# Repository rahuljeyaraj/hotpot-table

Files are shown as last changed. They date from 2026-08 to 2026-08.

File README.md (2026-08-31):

<p align="center">
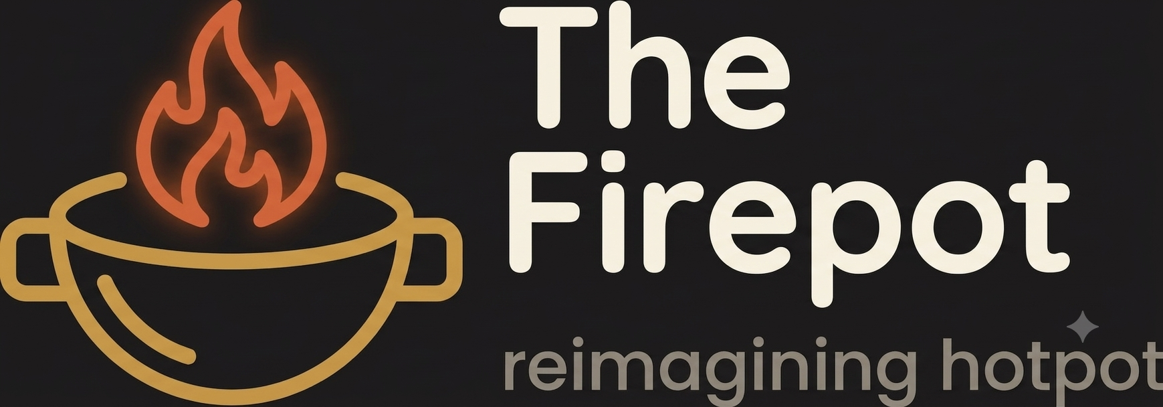
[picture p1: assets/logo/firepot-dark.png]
The Firepot — reimagining hotpot
  
</p>

<h1 align="center">The Firepot</h1>

<p align="center">
  A self-serve hotpot counter that weighs your bowl, prices it as you fill it, and sets itself on fire. Responsibly.
</p>

---

Eight ingredient bins are set into a tabletop of projector screen fabric. A
projector hangs above and lights the whole surface; a camera beside it watches
your hands. Every name, price, calorie count, tasting note, cart line and the
entire checkout is projected light landing on the table itself — right where a
person stands with a bowl in one hand and tongs in the other.

Each bin sits on a load cell. Take 60 g of dried eel and the cart on the near
edge of the table says so, priced, before you have put the tongs down. Tip some
back and the number falls. Pick a broth, pick a spice level, and a QR code
appears on the table for an itemised receipt on your own phone.

The whole interface is projected. There is no screen, no kiosk and nothing to
touch.

> **Build guide:** [`docs/HACKSTER.md`](docs/HACKSTER.md) is the full write-up —
> the story, the bill of materials, the wiring, the plywood cutting plan, and
> what the thing feels like to use.

---

## How it works

<p align="center">
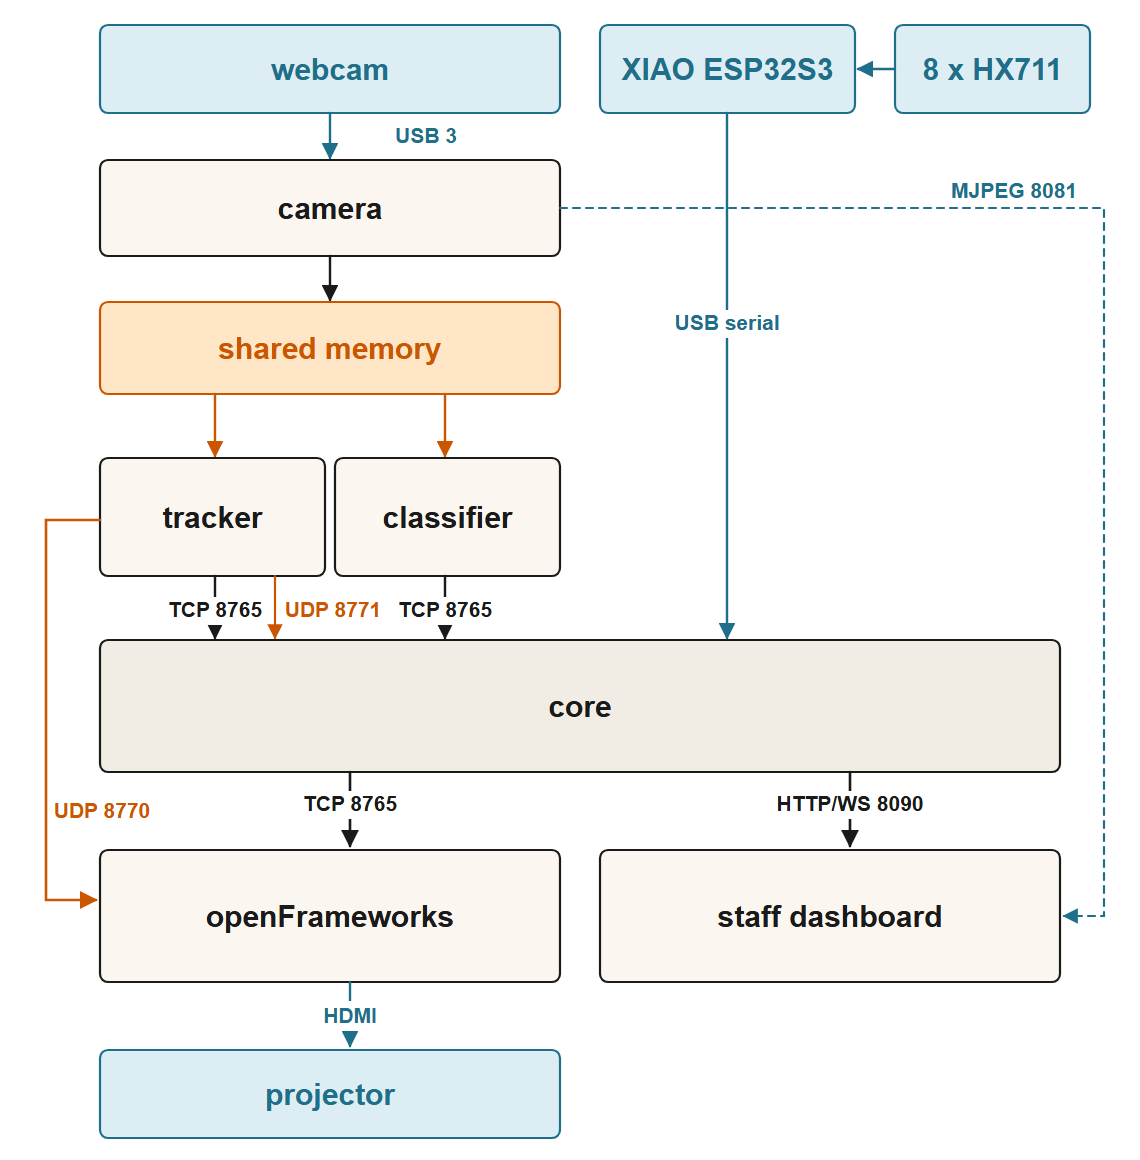
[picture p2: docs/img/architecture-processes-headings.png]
Five processes and four transports, from the webcam and load cells down to the projector
  
</p>

Five processes, none of which shares a variable with any other. `python run.py`
starts and supervises all of them, waits for each to report ready, merges every
log into one stream, and restarts anything that dies. Every process reconnects
forever, so any of them can come and go while the table carries on.

| Process | What it owns |
| --- | --- |
| `core` | Every price, every rule and every word. The state machine, the cart, the load cells, the orders database, the staff dashboard. |
| `of` | The projected table. A dumb renderer — it draws what it is told and holds no opinion. |
| `camera` | Frame capture, exposure/white-balance control, the shared-memory frame ring, and an MJPEG stream for the dashboard. |
| `tracker` | MediaPipe hand tracking over a window that follows the hand, emitting one cursor in projector pixels. |
| `classifier` | Bin crops, dataset capture, and ingredient recognition. |

A sixth process, `voice`, is started alongside these but is still a stub — it
connects, heartbeats and does nothing else.

Three kinds of traffic get three kinds of transport, each chosen for how the
data goes stale:

- **Cursor packets** go over UDP and the reader drains the socket, keeps the
  newest and throws the rest away. A queued cursor is worse than a lost one —
  the hand visibly walks back through its own history.
- **Camera frames** are six megabytes each, thirty times a second, so they go
  through a shared-memory ring with a seqlock. `core` never imports that
  module at all; the process that handles money has no way to touch a pixel.
- **State and control** go over TCP JSONL, one message per line.

There is exactly one coordinate system on the wire — projector pixels,
1920×1080 — so no two processes can disagree about where a bin is.

Further reading: [`docs/HOTPOT_ARCHITECTURE_v3.md`](docs/HOTPOT_ARCHITECTURE_v3.md)
is the authoritative design document; [`docs/VISUAL_LAYER.md`](docs/VISUAL_LAYER.md)
covers the renderer.

## Hardware

- **8 ×** 1 kg load cells with HX711 amplifiers, one per bin
- **1 ×** Seeed Studio XIAO ESP32S3, streaming all eight channels over USB
- **1 ×** 1080p projector, mounted on the wall right against the ceiling and
  aimed straight down, covering the full 1524 mm width of the table; squared
  up with its own 4D keystone
- **1 ×** 1080p webcam, zip-tied to a batten off the projector's mount and
  looking down at the same table — it hangs upside down on this build
- **1 ×** mini PC host (developed against an ASUS NUC 14 running Windows 11)
- Plywood, projector screen fabric, and a kilogram of gold PLA

Printable parts (`.3mf` plates, ready to slice) are in
[`hardware/3d-printed/`](hardware/3d-printed/); the KiCad project for the
load-cell harness is in [`hardware/firepot-loadcells/`](hardware/firepot-loadcells/).
The bill of materials with links, the wiring, and the cutting plan are all in
[`docs/HACKSTER.md`](docs/HACKSTER.md).

## Repository layout

```
config/            system.json — ports, thresholds, device selection
data/              catalogue.json, menu.json, locales/{en,zh}.json
firmware/loadcells/  PlatformIO firmware for the XIAO
hardware/          3D-printable parts and the KiCad schematic
of/hotpot-table/   the openFrameworks app (the projected table)
python/hotpot/     core, camera, tracker, classifier, voice, common
python/tests/      the unit test suite
tools/             dataset export, diagram rendering, rig utilities
run.py             the launcher and supervisor
```

## Getting started

### 1. Put it inside an openFrameworks tree

The Visual Studio project walks five levels up to find openFrameworks, so this
repository has to live at `apps/myApps/hotpot-table`. Download
[openFrameworks 0.12.1](https://openframeworks.cc/download/), unzip it, and
clone into it:

```
cd openFrameworks/apps/myApps
git clone https://github.com/rahuljeyaraj/hotpot-table
```

### 2. Build the table

`ofxGui`, `ofxOsc` and `ofxNetwork` ship with openFrameworks.
[ofxFlowTools](https://github.com/moostrik/ofxFlowTools) — the fluid solver
behind the fire — is a separate download into `openFrameworks/addons/`, and it
needs a patch before it will build:

```
cd openFrameworks/addons/ofxFlowTools
git apply ../../apps/myApps/hotpot-table/of/patches/ofxFlowTools.patch
```

The patch replaces two constructs the current compiler rejects, and fixes a
density lookup in the buoyancy and diffusion shaders that samples a texture at
a different resolution from the one it renders at.

Then open `of/hotpot-table/hotpot-table.sln` and build the **Debug**
configuration — that is the binary the launcher starts. Set `HOTPOT_OF_BIN` to
run something else.

### 3. Install the Python side

One interpreter for the whole tree:

```
pip install -r python/requirements.txt
```

### 4. Flash the XIAO

```
cd firmware/loadcells
pio run -t upload
pio device monitor
```

A working board probes all eight cells and then streams `raw <c0> ... <c7>` at
115200 baud. If a cell is missing, the probe names the pin and says whether the
data line is floating (open wire or unpowered HX711) or driven high (check the
clock).

### 5. Point it at your own rig

Three values:

- `SCALE_PORT` in `python/hotpot/core/main.py` — the XIAO's serial port.
  `pio device monitor` names yours.
- `camera.windows_device_index` in `config/system.json` — which webcam.
- `of/hotpot-table/bin/data/display.txt` — the projector's desktop origin as
  `x,y`. Start the app once; it writes the file and logs every monitor it found
  with its origin, so you can fill in the right one.

## Running

```
python run.py
```

Everything starts, in order, with one merged log to the terminal and to
`logs/hotpot-<date>.log`.

| | |
| --- | --- |
| `python run.py --replace` | stop whatever is running, start fresh |
| `python run.py --stop` | stop a detached instance |
| `python run.py --only core,of` | start the table alone, camera unplugged |
| `python run.py --no-restart` | leave a crashed process dead so you can read its traceback |

The staff dashboard is at `http://<host>:8090` from any device on the same
network, phone included.

## The staff dashboard

A **Serving** switch at the top opens and closes the table. Turn it off and
nothing bills, so staff can reach across the bins and swap trays without
registering as a customer's pick. Every calibration control is refused while it
is on.

- **Bins** — eight cards with live weights, an ingredient dropdown each, restock
  alerts under 50 g, and the tare/calibrate controls. Taring runs on all eight
  bins from a single capture window.
- **Setup** — mark the four table corners on the live camera view, lay a grid
  over the flattened result to place the bins, then nudge a second grid with the
  arrow keys while watching the real projected light until it lines up. That
  last step is the only verification that can actually fail, and it has to be
  done by a human looking at the table.
- **Capture** — photograph the bins to build a training dataset, one burst at a
  time. Export with `tools/export_edgeimpulse.py`.
- **Developer** — hand skeleton overlay, classifier guesses, camera controls,
  per-process health, and a live plot of each load cell (raw against filtered)
  with the filter windows adjustable while you watch.

## Calibration

Turn **Serving** off first. Geometry, in the Setup tab, in card order: four
corners → camera bin grid → projector bin grid. Then scales, in the Bins tab:
empty every bin and tare all eight, then calibrate each one against a known
mass. A fit under ten counts per gram is refused — that means the cell has come
loose or the weight was too light. Finally set what each bin holds.

To check the table before any load cells exist, run
`python run.py --only core,of` and use the Developer tab's per-bin
**Pick** / **Put back** buttons, which drive the whole flow through to the
token number.

## Tests

```
python -m unittest discover -s python/tests
```

The suite runs with no camera, no projector and no XIAO attached — every module
that talks to hardware takes the open call as a parameter, so the arithmetic
that can silently mis-bill is testable on a bare machine.

## Documentation

| | |
| --- | --- |
| [`docs/HACKSTER.md`](docs/HACKSTER.md) | Build guide: story, BOM, wiring, cutting plan, assembly |
| [`docs/HOTPOT_ARCHITECTURE_v3.md`](docs/HOTPOT_ARCHITECTURE_v3.md) | The authoritative design document |
| [`docs/VISUAL_LAYER.md`](docs/VISUAL_LAYER.md) | Renderer spec: bins, halo, fire, cart |
| [`docs/ROBOFLOW_PATHWAY.md`](docs/ROBOFLOW_PATHWAY.md) | The second classifier training/deploy path |
| [`docs/INGREDIENT_SUBSTITUTES.md`](docs/INGREDIENT_SUBSTITUTES.md) | Which prop stands in for which ingredient, and why |

## License

MIT — see [LICENSE](LICENSE).

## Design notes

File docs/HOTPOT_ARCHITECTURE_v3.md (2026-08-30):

# HOTPOT TABLE — ARCHITECTURE & BUILD SPECIFICATION v3.0

**Status:** authoritative. Supersedes all Stage 1–2 design notes.
**Target:** Seeed "Make a Sign" Interactive Signage Contest 2026.
**Audience:** Claude Code instances implementing this system, and the sole developer (RS).

---

## 0. HOW TO USE THIS DOCUMENT

This document is the ground truth. `CLAUDE.md` in the repo root is a short pointer to it plus current status.

Rules for any Claude Code instance working from this document:

1. **Work one milestone at a time.** Never start milestone N+1 before N's acceptance test has been run by a human on the physical rig.
2. **Within a milestone, work one step at a time.** Commit after each step. Stop after the commit and report back.
3. **Never assume an external API.** Where this document names a library function, verify it exists in the installed version before building on it. Three separate design errors in this project's history came from trusting remembered APIs. Specific known traps are flagged inline as **VERIFY**.
4. **Every check must be capable of failing.** If a verification would pass regardless of whether the code is correct, it is not a verification. Flagged inline as **TRAP**.
5. **Physical observation beats screenshots.** A framebuffer capture proves the renderer drew something. It does not prove the projector put it on the right piece of table. State which kind of evidence you have.
6. RS is dyslexic. Reports are short. One thing at a time. Confirmation questions name the single specific thing being confirmed.

---

## 1. WHAT THIS PRODUCT ACTUALLY IS

### 1.1 What this format is called

**English name: Hot Pot. Chinese name: 称重火锅 (chēngzhòng huǒguō) — weigh-by-weight hot pot.**

An earlier draft of this document claimed the pick-and-weigh mechanic was specific to 麻辣烫 (málàtàng) and that calling it "hot pot" would read as inauthentic. **That claim was wrong and is retracted.** The mechanic is not diagnostic — it runs under at least three names, and businesses using it overwhelmingly brand themselves as hot pot.

Evidence:

- Tang Bar (San Mateo) calls itself hot pot and runs exactly our flow: <cite index="40-1">diners select their ingredients from a buffet-style ingredient bar and weigh their selections to determine the price; after choosing their soup base, the staff cooks the hot pot for them.</cite> The owner frames it explicitly as hot pot for people who want the meal without the cooking.
- Big Way Hot Pot: <cite index="44-1">after you have filled your pot it is weighed at the counter and you pay in exchange for a number; all your raw ingredients are cooked in their back kitchen with your chosen broth.</cite>
- The identical mechanic also runs as 冒菜 (màocài): <cite index="39-1">customers select ingredients from a buffet table into baskets, choose a broth style, then hand everything to a staffer to have the hot-pot bowl assembled and cooked in the kitchen; payment is by total weight of ingredients at $3.99 per 100 grams.</cite>
- And as 麻辣烫: <cite index="18-1">grab a bowl and tongs, select from meats, vegetables, mushrooms, noodles and tofu products, the selection is weighed to determine the price, and everything is cooked in your chosen broth.</cite>

**Naming decision and its reasoning:**

"Hot pot" is the *broad* claim; "malatang" is a *narrow* one. A narrow claim gives a judge a target — if the broth on the day is not málà, the name is wrong. The broad claim is never wrong, and it is demonstrably correct for this format.

For the Chinese UI, **称重火锅** is used rather than plain 火锅. It is accurate, and it signals knowledge of the specific format rather than the generic word. 自助火锅 (self-serve hot pot) is an acceptable alternative if 称重火锅 reads awkwardly to a native speaker — **ask one before the contest.**

### 1.2 What the research does establish

The naming claim was wrong. The operational details are correct under any of the three names, and they are what make the build read as authentic:

- Pricing is conventionally **per 100 g**. Shops differ on whether all items share one rate or each has its own. <cite index="12-1">A commonly quoted figure is roughly $3 per 100 grams.</cite> Our per-item `pricePer100g` is the more sophisticated variant and is correct.
- **Broth choice is a required step**, not polish. Every source describes it as one of the defining choices alongside the ingredients themselves.
- **Spice level is a required step.** <cite index="16-1">Picking your own ingredients and adjusting the spice level yourself is the defining feature from the diner's point of view.</cite> Level 0 must genuinely exist as a plain option.
- **The order ends with a number, not a meal.** <cite index="40-1">Diners wait for their order number to appear on a screen and then collect the dish.</cite> This is exactly why the checkout loop (§18) matters — it is the real operational flow, not an invented feature.
- Tongs and a bowl, self-service, one diner at a time filling their own bowl. This confirms the multi-diner attribution question stays out of scope (§24.4).

### 1.3 Consequences for the build

| Decision | Rationale |
|---|---|
| Product name: **Hot Pot** (en) / **称重火锅** (zh) | Demonstrably correct for this format, and the broad claim carries no risk. |
| Repo, code identifiers and file names keep `hotpot-*` | Already correct. Nothing to rename. |
| Broth selection is a required step | One of the defining choices. |
| Spice level 0–3 is a required step | <cite index="16-1">Adjusting the spice level yourself is a defining feature.</cite> Cheap to build, high authenticity return. |
| The order ends with a **numbered handoff** | <cite index="40-1">The real flow ends with an order number and a collection.</cite> |
| Ingredient names in Chinese must be the specific real names | 香菇 for shiitake, not a generic 蘑菇. This is where a Chinese judge actually looks. |

### 1.4 The machine it ships on — RESOLVED

This lives in section 1 rather than in a hardware appendix because it is now a fixed input to almost every downstream number in this document, and it should be read before §10.4, §11.2 and §14.6 rather than after.

The deploy target is the **Seeed ODYSSEY-X86J4125800 v2** (SKU 102110767, ~$218). It replaces "reComputer, model unidentified" everywhere that phrase appears.

| | |
|---|---|
| SoC | Intel Celeron **J4125**, Gemini Lake Refresh, Goldmont Plus |
| Cores | **4 cores / 4 threads — no hyper-threading** |
| Clocks | 2.0 GHz base, 2.4 GHz all-core turbo, 2.7 GHz single-core turbo |
| TDP | 10 W |
| Vector ISA | **SSE4.2 only — no AVX, no AVX2** |
| iGPU | Intel UHD Graphics 600, **12 EUs**, 250–750 MHz (~144 GFLOPS FP32) |
| RAM | **8 GB LPDDR4, soldered, not upgradeable**, shared with the iGPU (~38.4 GB/s total) |
| Storage | 64 GB eMMC on board, microSD, M.2 Key M 2242/2280 (PCIe 2.0 ×4, NVMe), M.2 Key B (SATA III / USB 2.0 / SIM), 1× SATA III |
| Video | HDMI 2.0a 4K@60 + DisplayPort 1.2 over USB-C 4K@60, two displays |
| USB | **1× USB 3.1 Type-A, 1× USB 3.1 Type-C, 2× USB 2.0 Type-A** |
| Network | Dual **2.5 GbE**, Wi-Fi 5 dual-band, Bluetooth 5.0 |
| Co-processor | **RP2040**, Arduino-programmable (v1 had a SAMD21 — v2 does not) |
| Headers | 40-pin Raspberry-Pi-compatible, 4-pin PWM fan, RTC battery |
| Power | 12–19 V via 5.5/2.1 mm barrel jack, or 5–12 V USB-C PD |
| Size | 110 × 110 mm |

**No feature in this document is cut to fit this board.** Everything specified still ships. What changes is where the adaptive controllers *start*, what gets measured rather than assumed, and a short list of parts to order alongside the board. The four facts below are the ones that actually propagate.

**(a) Exactly 4 cores, no SMT.** §10.4's affinity plan was written speculatively and happens to fit precisely — four cores, four assignments. That is now finalised there, with the caveat that "fits precisely" means zero headroom for the OS.

**(b) No AVX2.** This is the least obvious fact on the list and the most dangerous. Goldmont Plus stops at SSE4.2. Every x86 inference path we depend on — MediaPipe's XNNPACK backend, TFLite, and whatever Edge Impulse compiles into a `.eim` — has AVX2 fast paths and will either fall back to much slower SSE code or, in the bad case, be built AVX2-only and die with SIGILL on first inference. **A binary that runs on the development machine proves nothing about this board.** New VERIFY items in §11.2 and §19.1.

**(c) The iGPU is small and shares memory with the CPU.** 12 EUs at 750 MHz is roughly 144 GFLOPS, somewhere between 15× and 30× less than the Arc part the 60 FPS figure in §14.6 came from. The sharper limit is bandwidth, not shader math: a GPU fluid solver is a chain of full-frame ping-pong passes, and it is drawing on the same ~38.4 GB/s that four busy CPU cores are already using. A 20-iteration Jacobi pressure solve at 480×270 RGBA32F moves on the order of 120 MB per frame — about 7 GB/s at 60 fps, before advection, vorticity, particles or the light pass. This is why §14.6 now starts at the bottom of the ladder and climbs, and why RGBA16F is worth trying: it halves every one of those numbers.

**(d) One USB 3 Type-A port.** The peripheral set fills the board exactly, so the allocation is not free choice:

| Device | Port | Why |
|---|---|---|
| Camera | **USB 3.1 Type-A** | The only port with the bandwidth. Never behind a hub, never sharing with the others. §5.4 and §6.6 assume this. |
| XIAO load cells | USB 2.0 Type-A | Serial at 115200 needs nothing more (§4.9). |
| Microphone, *if* the webcam has no capture device | USB 2.0 Type-A | The open VERIFY at §3. If the webcam does expose one, this port stays free — that is the only spare port in the build. |
| Projector | HDMI | 2.0a, 4K@60 capable. |
| Power | **Barrel jack, not USB-C** | Powering over USB-C consumes the Type-C port. Use 12 V on the barrel jack and keep Type-C free. |

There is no port left for a keyboard and mouse at deploy time. **Bring a powered USB hub for bring-up**, and do not leave it in the build — staff operation is the browser view over LAN (§12), which is exactly why that design is right.

**Parts to order with the board:**

1. **An NVMe SSD in the M.2 Key M slot.** 64 GB of eMMC has to hold Ubuntu, an openFrameworks tree plus build artifacts, the models, `orders.sqlite3`, logs, and the dataset that §12.7 captures image-by-image. It will not fit comfortably, and eMMC random write is poor enough that SQLite commits and dataset capture will both feel it. Cheapest risk removal available on this project. Put the OS on it; failing that, at minimum `datasets/`, `logs/` and `state/`.
2. **The 4-pin PWM fan.** See below.
3. **12 V barrel-jack PSU**, 3 A or better.

**Thermals are a real risk here, not a formality.** This workload pins four cores and the iGPU simultaneously and indefinitely, which is the worst case for a 10 W passively-cooled part, and it does so *next to a hot pot* — elevated ambient, steam, and airborne grease. Passive cooling that is fine on a bench will throttle in that environment, and a throttled J4125 loses clock across all four cores at once, which will present as the fluid degrading and the tracker slowing at the same time and will be debugged as a software problem. Mount the board away from the burner in a ventilated enclosure, fit the fan, and add package temperature and the throttle flag to the developer panel (§12.8) so the failure is legible when it happens.

**Two things the board offers that this design does not currently use**, recorded so the decision is deliberate rather than forgotten:

- **The onboard RP2040.** The load cells are already working on a XIAO over USB serial with frozen firmware (§4.9, §9.5). Moving them to the onboard RP2040 would remove a device and a cable and would be a genuinely good story for a Seeed contest, since it uses the board's distinguishing feature. It also means rewriting working firmware near a deadline. **Decision: keep the XIAO.** Revisit only if a USB port becomes the binding constraint.
- **The second 2.5 GbE port.** A contest hall's Wi-Fi is hostile and the staff tablet depends on the network (§12, and `camera.host_for_browser` in §8.6). Put one NIC on the venue LAN and hang a small travel router off the other as a private network for the tablet, or use the board's own Wi-Fi as an AP. Either way the staff view stops depending on the venue. Decide during M9 setup.

---

## 2. INVARIANTS

These are load-bearing. Violating one is a design regression, not a style choice.

**I1 — Core owns all state.** Weights, cart, prices, bin map, geometry, FSM, locale, mode. No other process holds authoritative state.

**I2 — openFrameworks is a dumb renderer.** It receives resolved, semantic state (a finished string, a number, a rectangle, a highlight enum) and draws it. It computes nothing it could be told. It retains only **rig calibration constants** — the keystone homography, and the two I9 illuminant values `field_level` and `white_floor` (§8.6) — plus frame-to-frame tweening. These are properties of the physical installation, measured once and read at startup, not application state: core cannot resolve them because they describe the projector, not the transaction.

**I3 — Core never touches a frame.** No pixel data enters the core process. Ever.

**I4 — Price is cumulative and absolute.**
```
removedGrams[i] = max(0, startWeightGrams[i] - binWeightGrams[i])
price[i]        = (removedGrams[i] / 100.0) * pricePer100g[i]
```
Never sum per-event deltas. Two absolute weights subtracted cannot bake in a dropped or doubled event. There is **no put-back branch and none is to be added** — a put-back raises the weight, lowers the difference, lowers the total. The refund *is* the arithmetic.

**I5 — The 10g deadband is display-only.** It never enters price maths. It **snaps to current truth** when the gap reaches 10g, so small picks accumulate and are eventually shown. The wrong version — "ignore events under 10g" — throws picks away. Do not write it.

**I6 — Re-baseline, never re-tare.** `startWeightGrams[i] = binWeightGrams[i]`. Nothing becomes zero. The word "tare" is reserved for the load-cell zero-point calibration in staff view, which is a different operation on a different quantity.

**I7 — Food position is not fixed.** Trays get swapped mid-service. The bin→item map is live data written by the classifier, never a constant. Price follows the food, not the bin.

**I8 — Distinguish states by hue at full chroma, not by brightness.** Brightness is spent on illumination (I9) and is therefore not available as a signalling channel — everything on the table sits near the top of the range, so a "dimmer" state reads as a rendering fault rather than as a state. Hues must additionally be **luminance-matched to each other**, or a state change reads as the table brightening rather than as the state changing. Already measured on the rig: the dwell-progress green had to come down from 255 to 115 to sit at the same luminance as the 200-red it replaces, because a full-value green on a light field lands at about 1.4:1 — worse than the dim cyan that had already been rejected at the table.

**I9 — The projected field is the illuminant, not a background.** The projected field is the only light this system controls and the brightest light on the table. **The dark room this invariant was originally written against was never achieved** — room light was uncontrolled on every real rig session (§24.1), and §25's risk table already says the design does not invert under ambient, it just stops being the *only* light. The invariant stands either way: the requirements below are what keep the food lit and the tracker fed, and ambient light is a bonus that cannot be relied on. Three consequences, none of them aesthetic:

1. **Every tray cutout carries a flat, pure-white patch at full field level.** Not black. A black rectangle over a cutout is not "leaving the food alone" — with no ambient to fall back on it is the food in total darkness, which starves the classifier rather than protecting it. The choice is projector light or no light, and the patch also lights the back of the hand exactly when the hand is over a bin.
2. **Nothing coloured, patterned, textured or animated ever reaches a cutout.** The objection this invariant was originally written against was real, but it was about a *coloured, patterned* image washing pink and white over the food — not about light as such. Flat white is neither. Fluid, gradients, grid lines, diagonals, text and low-stock tints are all excluded from the bin patches. §13.2 makes this structural rather than something to remember.
3. **The rest of the table stays above a white floor**, bright enough that the back of the hand is always lit for the tracker. Colour is free above that floor; darkness is not. The floor and its mechanism are specified in §13.2.

**There is no longer any exception.** M4.3's dot-projection calibration was the one thing that inverted the field completely (black field, white dots, a dark exposure to keep them separable), and it has been removed outright — replaced by a manual 4-corner tool (§12.6) that reads the already-lit field like every other setting-mode activity. See §24.1 for why the dot-pattern approach was abandoned rather than tuned further.

**I10 — Camera near-vertical.** Hand-position error = hand height ÷ tan(elevation angle). At 40° a 100mm-high hand lands 119mm off — the wrong bin. At 80° it is 18mm. **The camera elevation angle has never been measured. It must be measured before M4.**

---

## 3. PROCESS ARCHITECTURE

Six Python processes plus one C++ process. Processes, not threads: separate interpreters, separate cores, no shared GIL. Jitter is the enemy and oF needs a core to itself.

| Process | Owns | Never does |
|---|---|---|
| `camera` | `/dev/video0`, the shared-memory frame ring, the MJPEG HTTP server | Any analysis. It is deliberately the dumbest process in the system and must stay that way. |
| `tracker` | MediaPipe Hands, hand role assignment | Decide anything. It reports positions and roles. |
| `classifier` | Food classification **and projected-dot detection** — all frame analysis that is not hand tracking | Run in serving mode. It sleeps unless core wakes it. |
| `voice` | The microphone (ALSA), keyword spotting | Interpret meaning. It reports which keyword fired. |
| `core` | Everything in I1, the staff-view HTTP+WS server, the serial thread, the order database | Touch a frame (I3). Block. |
| `of` (C++) | The projector output, the keystone homography, tweening, the fluid simulation, **audio output** | Hold state or compute logic (I2). |
| `run.py` | Launching, supervising, restarting, and killing all of the above | Any application logic. |

### 3.1 Why the microphone is not in the camera process

The webcam's microphone is almost certainly the same physical USB device as the camera, but it is a **different kernel device node** — ALSA, not V4L2. Two processes opening two different nodes on one USB device is fine. There is no ownership conflict, so nothing forces camera and voice together, and the camera process must stay dumb.

**VERIFY at M0:** run `arecord -l` and confirm the webcam exposes a capture device. If it does not, voice needs a separate USB mic and that is a hardware order, not a code change.

### 3.2 Why the classifier owns dot detection

Projected-dot calibration needs someone to find dot centroids in a camera frame. Core cannot (I3). Camera must not (it stays dumb). The classifier already attaches to frames and already runs only in setting mode — and calibration *is* a setting-mode activity. It fits with zero new machinery. The classifier is therefore better understood as "the vision process": one process, all frame analysis except hands.

### 3.3 Restart-tolerant topology

**Core is the TCP server for every control link. Everyone else is a client and reconnects with backoff.** One rule, and it makes start order almost irrelevant: any process may start, die and restart in any order and the system reconverges. `camera` is additionally a server (shm creator + MJPEG). `run.py` still starts them in a sensible order to reduce noise in the logs, but correctness does not depend on it.

---

## 4. TRANSPORT SPECIFICATION

Three traffic classes with different failure needs. This was argued out and is settled.

| Class | Transport | Why |
|---|---|---|
| Frames | POSIX shared memory ring | Never send pixels through a socket. |
| Cursor (tracker → oF, tracker → core) | UDP, localhost, one datagram per frame | A lost cursor packet is worthless 16ms later. TCP would *queue* stale ones — a 200ms hiccup then delivers a burst in order and the hand visibly replays through history. That is exactly the jitter six processes exist to avoid. |
| Control (everything else) | TCP, newline-delimited JSON (JSONL), UTF-8 | These must not vanish. A dropped "enter setting mode" wedges the system. |

**Receiver rule for UDP: drain to latest.** Read the socket non-blocking until it is empty, keep the highest `seq`, discard the rest. Never process a backlog.

**Why not ZeroMQ for everything:** it is a new build dependency on both sides, and the side that is risky is the oF build on the ODYSSEY (§1.4) — a board with 64 GB of eMMC where every added dependency is also disk and build time. `ofxNetwork` ships with openFrameworks and has both UDP and TCP in the box — zero new dependencies on the Linux build. The one thing ZMQ would genuinely buy is automatic reconnect, and §19 provides that in ~40 lines.

### 4.1 Ports and names (defaults, all in `config/system.json`)

| Name | Default | Owner |
|---|---|---|
| `core.control_port` | 8765 | core (TCP server) |
| `core.web_port` | 8090 | core (HTTP + WebSocket) |
| `camera.mjpeg_port` | 8081 | camera (HTTP) |
| `cursor.of_port` | 8770 | of (UDP listener) |
| `cursor.core_port` | 8771 | core (UDP listener) |
| `frames.shm_name` | `hotpot_frames` | camera |

### 4.2 Control link — common envelope

Every JSONL line is an object with a `t` (type) field. Every client opens with `hello` and heartbeats every 1000ms.

```json
{"t":"hello","who":"tracker","pid":4412,"ver":3}
{"t":"hb","ts":1754838400.117}
```

Core replies to `hello` with the client's current configuration, so clients hold no config of their own beyond how to find core:

```json
{"t":"welcome","who":"tracker","cfg":{"homography_cam_to_stage":[[...]],"stage":[1920,1080],"hand_model_complexity":1,"emit_hz":60}}
```

**Core marks a client dead after 3 missed heartbeats (3s).** Death is surfaced on the staff view status pips and, if it is `of` or `camera`, on the table.

**The tracker's `cfg` example above is stale** (also missing `mirror_handedness`/`view_rotation_deg`, added 2026-08-12) — not rewritten here, per this doc's own precedent of flagging rather than line-editing a payload example every time a field is added; `core/main.py`'s `_tracker_cfg()` is the source of truth. **2026-08-14: `mediapipe_enabled` (bool) added** — `false` for the whole of SETTING mode, `true` otherwise. Pushed on `welcome` and re-pushed immediately by `_handle_set_mode` on every real mode transition, the same live-push path `mirror_handedness` already uses. `tracker/main.py`'s `tick()` skips `backend.detect()` entirely while it is `false` — staff are reaching into the frame to swap trays, which is exactly the input MediaPipe would otherwise track as a hand.

### 4.3 core → of

Sent at a fixed 60Hz, whether or not anything changed. A fixed-rate state stream means oF's tweener always has a fresh target and never has to guess whether silence means "no change" or "core is dead."

```json
{"t":"state","seq":90211,"ts":1754838400.117,
 "mode":"serving",
 "locale":"zh",
 "fluid":{"style":"mala","enabled":true,"intensity":0.6},
 "bins":[
   {"i":0,"label":"香菇","sub":"¥12.00/100g","grams":418,"picked":38,"price":4.56,
    "hl":"hover","stock":"ok","resolved":true}
 ],
 "total":{"amount":41.20,"text":"¥41.20"},
 "widgets":[
   {"id":"done","kind":"button","rect":[1480,880,380,140],"label":"结账",
    "dwell":0.42,"enabled":true,"style":"primary"}
 ],
 "overlay":{"kind":"none"}
}
```

Notes that are not optional:

- `label` and `text` are **already resolved strings in the current locale**. oF does no lookup (I2). It only needs `locale` to pick a font.
- `rect` is in **stage space** (§5), always `[x, y, w, h]`.
- `hl` ∈ `none | hover | picking | picked | lowstock | disabled`.
- `mode` ∈ `serving | setting` (§9.1). Derived from the FSM state, never stored separately — two places that can disagree about which mode the table is in is the failure this field exists to prevent. oF defaults it to `serving` when absent, deliberately: a line that somehow lost the field must not paint `SETTING — NOT BILLING` over a table that is billing.
- `overlay.kind` ∈ `none | recap | qr | uncalibrated | error`. **`calibrating` no longer exists** — it was M4.3's dot-projection wizard's black-field overlay, and both are gone (see §12.6, §24.1). `overlay.dots` is gone with it.
- `bins` always has exactly 8 entries. An unresolved bin has `resolved:false`, an empty `label`, and bills nothing.

### 4.4 core → of, one-shot events

Separate from `state` because `state` repeats and a repeated sound would fire 60 times a second.

```json
{"t":"evt","kind":"sound","id":"dwell_fire","gain":1.0}
{"t":"evt","kind":"burst","at":[640,300],"style":"pick","strength":0.8}
{"t":"evt","kind":"stream","from":[640,300],"to":[1660,940],"style":"price"}
```

Events are fire-and-forget. If oF misses one because it just restarted, nothing breaks.

### 4.5 of → core

oF sends only heartbeats and telemetry. It never sends input.

```json
{"t":"stat","fps":59.8,"sim_res":[480,270],"gpu_ms":9.1,"dropped":0}
```

### 4.6 tracker → of and tracker → core (UDP)

One datagram per camera frame, sent to both ports. Compact JSON — at 60Hz and ~150 bytes this is free, and being human-readable during bring-up is worth more than the bytes.

```json
{"seq":98123,"ts":1754838400.117,"hands":[
  {"id":3,"role":"pointer","x":941.2,"y":510.8,"conf":0.93},
  {"id":4,"role":"ambient","x":300.1,"y":700.4,"conf":0.81}
]}
```

`x,y` are **stage space** floats. `role` ∈ `pointer | ambient`. See §11.3 for role assignment.

### 4.7 core ↔ classifier

```json
{"t":"cmd","id":17,"op":"classify","rects":[[x,y,w,h], ...8],"mode":"once"}
{"t":"cmd","id":18,"op":"classify","rects":[...],"mode":"live","hz":2}
{"t":"cmd","id":19,"op":"stop"}
{"t":"cmd","id":21,"op":"capture","rects":[...],"labels":["mushroom",...],"burst":5,"interval":2}
```
```json
{"t":"result","id":17,"bins":[{"i":0,"label":"mushroom","conf":0.94},...],"ms":42}
{"t":"capture_progress","id":21,"shot":2,"burst":5,"interval":2}
{"t":"captured","id":21,"files":["datasets/captures/mushroom/17548384001.jpg",...]}
```

**`detect_dots` no longer exists.** Automated dot-projection calibration
was removed outright — it needed a dark, room-light-free rig this project
never achieved (see CLAUDE.md's M4h/M4i/M4j) — in favour of the manual
4-corner tool in §12.6. `classifier/dots.py` is deleted, not disabled.

**`capture`'s `burst`/`interval` (2026-08-13, was `burst`/`seconds`
naming a total period).** `interval` is seconds **between** one shot and
the next, not a total period divided across `burst` — the old shape made
raising the frame count silently shrink every gap, exactly backwards from
what an operator wants when they raise it to get more time to rearrange
the tray. `capture_progress` is new: one broadcast per shot, sent by the
classifier and relayed by core to every tablet **without** resolving the
command's own reply — `core/main.py`'s `_send_classifier_cmd` waiter only
ever completes on `captured`, the same correlate-by-`id` discipline as
every other classifier reply. §12.7 has the operator-facing half (the
counter and the countdown).

`rects` are **camera space** (§5) — the classifier never sees stage space.

> **Superseded on one point (§5.3's addendum has the full reasoning):** the `capture` command now also carries `"h":[[...],[...],[...]]` (the 3x3 `H_cam_to_stage`) and `"stage_size":[1920,1080]` alongside `rects`. Core never touches a frame (a hard invariant), so it cannot warp the raw frame itself — the classifier does, via `common.geometry.warp_frame_to_stage`, before cropping. `rects` are still 8 `[x,y,w,h,bin_i]` entries, just measured in that warped canvas's own pixel space (`core/bin_grid.py`'s camera grid) rather than raw sensor pixels.

### 4.8 voice → core

```json
{"t":"kw","word":"done","conf":0.87,"lang":"zh","ts":1754838400.117}
```

The voice process reports **which keyword fired**, never what it means. Meaning is per-FSM-state and only core knows the state. "Done" in setting mode and "done" in serving mode are different actions.

### 4.9 XIAO → core (USB serial)

**VERIFY before writing the parser:** read `firmware/loadcells/src/main.cpp` and match its actual print format. Do not assume the format below — it is a description of intent, not a spec to code against.

Expected shape: one line per sample at ~78Hz, eight signed integers of raw HX711 counts. The parser must:
- be tolerant of partial lines at startup (the first line after open is usually truncated),
- discard any line that does not parse cleanly rather than crash,
- never block the core main loop (it runs in a thread, §9.5).

---

## 5. COORDINATE SPACES

This was an unresolved hole. It is now settled. Three spaces, one canonical.

### 5.1 The three spaces

| Space | Units | Who lives in it |
|---|---|---|
| **Camera space** | camera pixels, e.g. 0..1919 × 0..1079 | MediaPipe raw output, bin rects as dragged by staff, classifier crops |
| **Stage space** — **CANONICAL** | 1920 × 1080, origin top-left | Everything semantic: cursor, bin rects sent to oF, widget rects, core's zone tests |
| **Projector output** | the physical keystoned quad on the table | oF only, produced by the final warp |

### 5.2 Why stage space is canonical and not millimetres

Millimetres would need a physical measurement to anchor. Stage space needs none: it is oF's un-keystoned framebuffer, and the manual 4-corner tool (§12.6) produces a camera→stage homography **directly**, because the 4 stage corners are known fixed coordinates and the operator's clicks are matched against them after being keystoned onto the table by the same warp that will carry the UI.

`H_cam→stage` therefore **implicitly contains the keystone**. This has one consequence that must be written into the staff view as a warning:

> **Changing the keystone invalidates the camera→stage homography.** Re-run calibration after any keystone adjustment.

### 5.3 Who holds what

- **Core** computes and owns `H_cam→stage` (`state/homography.json`).
- Core pushes it to `tracker` in the `welcome` message. Tracker converts MediaPipe output to stage space before sending. oF and core therefore both receive stage-space cursors and never disagree.
- Core owns bin rects **in both spaces**: camera-space rects are the ground truth (staff dragged them there); stage-space rects are derived through `H_cam→stage`.
- Core pushes camera-space rects to the classifier and stage-space rects to oF.
- oF owns only the keystone, applied to the final composite.

**TRAP:** verifying the derived stage rects by reprojecting them back through the same `H` passes by construction, regardless of whether `H` points the right way. The only check that can fail is physical: project the derived rects and look at whether they land on the real trays. This trap has already been hit three times in this project in different disguises. Do not hit it a fourth.

> **Superseded (see `core/bin_grid.py`'s own module docstring for the full reasoning), not rewritten away here — this section's history matters.** The "camera-space rects derived into stage-space rects through one shared `H_cam→stage`" model above is no longer how bins are owned. It is now:
>
> - **Two independent bin grids, never derived from each other:** `state/bin_grid_camera.json` (4 horizontal + 8 vertical line positions, dragged on the camera's RECTIFIED table frame — `common.geometry.warp_frame_to_stage(frame, H_cam→stage, stage_size)`) feeds the classifier's crop and core's own hand-entered-bin hit test. `state/bin_grid_projector.json` (not built yet — a later, separate step) will feed oF's ring/cutout/fluid, dragged by watching the actual projected light on the table, no camera involved at all.
> - **A grid, not 8 independent rects**, in both spaces: two bins in the same row or column can no longer disagree about the edge they share, which 8 independently-dragged rects could.
> - `H_cam→stage` is still exactly what §5.2 describes and still the only thing that ties camera pixels to the projector's canvas — it is just no longer used to derive one bin geometry from the other. It is infrastructure for the table-crop warp, not a bridge between two rect lists.
> - **Why two grids and not one shared canvas**, restated because it is the point the old model got wrong: a single planar homography does not fully model either device's own lens distortion or mounting error, so "camera pixel `(x,y)` == projector pixel `(x,y)`" is true in principle and not to the pixel in practice. Each grid is closed by its own human verifying it in the space it actually feeds — the same TRAP discipline this section already argues for, just applied to two spaces that turned out to need independent verification, not one.
> - `state/bin_rects.json` (8 independent camera-space rects) is gone; do not resurrect it as a data source.

Doc §5.4 below still describes the underlying CSS-scaling discipline correctly (a value dragged on a CSS-scaled `<img>`/canvas must be converted to that element's own natural/buffer pixel space before it is stored) — it now applies to the bin grid's line positions on the RECTIFIED canvas, not to a rect on the raw feed. §8.4 and §12.6/§12.7 below are similarly superseded on this point; not line-edited in this pass.

### 5.4 The MJPEG scaling trap

Staff drag rects on an `<img>` element that is CSS-scaled and may be served at a different resolution than capture. Rects must be stored in **capture-space pixels**, not display pixels.

Implementation rule, in the browser:
```js
const sx = img.naturalWidth  / img.clientWidth;
const sy = img.naturalHeight / img.clientHeight;
// every mouse/touch coordinate is multiplied by sx, sy before being stored or sent
```
`naturalWidth` reflects what the server actually sent, so this is correct whether MJPEG is full-res or downscaled, and stays correct if the config changes.

---

## 6. THE SHARED-MEMORY FRAME RING

Single producer (camera), multiple readers (tracker, classifier). Lock-free, seqlock-verified. This is the standard pattern and there is no reason to invent anything.

### 6.1 Layout

One `multiprocessing.shared_memory.SharedMemory` segment named `hotpot_frames`.

```
offset  size    field
0       4       magic  = 0x48505446 ('HPTF')
4       4       version = 3
8       4       width
12      4       height
16      4       channels (3, BGR)
20      4       slot_count (default 8)
24      8       write_counter   (uint64, monotonic, published last)
32      32      reserved
64      N*24    slot headers: [frame_id:u64][ts_ns:u64][ready:u32][pad:u32] × N
64+N*24 N*W*H*C slot pixel data
```

### 6.2 Write path (camera)

```
slot = write_counter % slot_count
write pixels into slot
write slot header: frame_id = write_counter, ts_ns = now
memory barrier
write_counter += 1        # publication
```

### 6.3 Read path (tracker, classifier)

```
c1 = write_counter
slot = (c1 - 1) % slot_count
id1 = slot.frame_id
copy pixels out
id2 = slot.frame_id
if id1 != id2: retry     # torn read, writer lapped us
```

With 8 slots at 30fps a reader has ~260ms before it is lapped. Tearing should be effectively unobservable; the check exists so that when it does happen the frame is discarded rather than silently corrupted.

### 6.4 Staleness — how a reader knows camera died

`ts_ns` in the slot header. If `now - ts_ns > 500ms`, the camera is dead or stalled. The reader must:
- stop emitting (tracker sends nothing rather than sending a frozen cursor),
- report `{"t":"stat","frames_stale":true}` to core,
- keep polling; when frames resume, resume silently.

**This is the answer to "who notices when the camera dies": the consumers do, immediately, without asking anyone.**

### 6.5 One resolution, not several

The ring holds **capture resolution only** — the highest useful resolution the webcam offers. Consumers adapt:
- `classifier` crops at full res (it wants the detail).
- `tracker` downsamples with `cv2.resize` before MediaPipe (cheap, and MediaPipe wants small).
- `camera`'s MJPEG server encodes at `mjpeg_width` (config), independently.

A second ring at a second resolution would double memory bandwidth to save one `resize` per frame. Not worth it.

### 6.6 Camera capture settings

Request `MJPG` as the V4L2 pixel format if the webcam offers it, then decode on the host. Most USB webcams cannot deliver high resolution at high framerate in `YUYV` because of USB bandwidth; `MJPG` is how they get there. Enumerate at startup with `v4l2-ctl --list-formats-ext` and log the chosen mode.

Also at startup, disable anything that fights the classifier:
- auto-exposure → manual, fixed
- auto white balance → off, fixed
- autofocus → off, fixed

Changing exposure between the training set and inference is a classifier accuracy bug that looks like a model problem. Lock it and record the values in `state/camera_settings.json`.

**The projector field level is part of this set.** Since the field is the illuminant (I9), `field_level` and camera exposure are one coupled parameter, not two — and the coupled pair must be identical at capture time and at inference time, for exactly the reason above. Consequences:

- `field_level` lives in `config/system.json` (§8.6) as a percentage of full projector output. Default **100%**.
- It is **swept on the rig against camera exposure** during M3/M4 — projector at each level, camera exposure adjusted, look at the bin crops — and then frozen. It is a measured rig parameter, not a look chosen in code.
- The chosen value is mirrored into `state/camera_settings.json` alongside exposure and WB, so a single file answers "under what light was this dataset taken."
- **The bin patches are always at full level regardless of `field_level`.** `field_level` sweeps the field; the cutouts stay at the top of the range. "Fully lit" is not a level to be traded off.

---

## 7. REPOSITORY LAYOUT

```
hotpot-table/
├── CLAUDE.md                       # short: status + pointer to this doc
├── docs/
│   └── HOTPOT_ARCHITECTURE_v3.md   # this file
├── run.py                          # THE single entry point
├── config/
│   ├── system.default.json         # committed
│   └── system.json                 # gitignored, seeded from default on first run
├── state/                          # gitignored entirely — runtime state
│   ├── homography.json
│   ├── bin_rects.json
│   ├── loadcell_cal.json
│   ├── bin_map.json
│   ├── camera_settings.json
│   ├── session.jsonl               # write-ahead journal, §19.3
│   └── orders.sqlite3
├── data/                           # committed — content, not state
│   ├── catalogue.json
│   └── locales/
│       ├── en.json
│       └── zh.json
├── python/
│   ├── pyproject.toml
│   └── hotpot/
│       ├── common/
│       │   ├── framebus.py         # §6
│       │   ├── wire.py             # JSONL framing, reconnecting TCP client, TCP server
│       │   ├── cursorbus.py        # UDP send / drain-to-latest recv
│       │   ├── geometry.py         # homography fit, apply, invert
│       │   ├── atomicio.py         # write-temp + fsync + rename
│       │   ├── health.py           # heartbeat, status registry
│       │   └── log.py
│       ├── camera/main.py
│       ├── tracker/main.py
│       ├── classifier/
│       │   ├── main.py
│       │   ├── backend_ei.py       # Edge Impulse runner
│       │   ├── backend_stub.py     # deterministic fake, for M0–M6
│       │   └── dots.py             # projected-dot detection
│       ├── voice/
│       │   ├── main.py
│       │   ├── backend_ei.py
│       │   └── backend_stub.py
│       └── core/
│           ├── main.py
│           ├── fsm.py
│           ├── cart.py
│           ├── pricing.py
│           ├── scale.py            # serial thread + calibration maths
│           ├── binmap.py
│           ├── geometry_store.py   # rects in both spaces, homography
│           ├── orders.py           # sqlite, order queue, day summary
│           ├── journal.py          # §19.3
│           ├── i18n.py
│           └── web/
│               ├── server.py       # HTTP + WebSocket
│               └── static/         # staff view SPA, §12
├── of/hotpot-table/                # openFrameworks app
│   ├── src/
│   │   ├── main.cpp
│   │   ├── ofApp.h / ofApp.cpp
│   │   ├── StateLink.h/.cpp        # TCP client, JSONL, tweening
│   │   ├── CursorLink.h/.cpp       # UDP, drain-to-latest
│   │   ├── Stage.h/.cpp            # FBO stack + keystone
│   │   ├── FluidLayer.h/.cpp       # §13
│   │   ├── UiLayer.h/.cpp
│   │   └── AudioBus.h/.cpp         # §14
│   └── bin/data/
│       ├── keystone.json
│       ├── fonts/
│       └── audio/
├── firmware/loadcells/             # UNCHANGED — it works
├── models/
│   ├── ingredients-x86_64.eim      # gitignored if large; see models/README.md
│   ├── keywords-x86_64.eim
│   └── README.md                   # provenance: EI project id, version, val acc
├── assets/
│   └── tts_src/                    # phrase lists for offline TTS rendering
├── datasets/                       # gitignored
│   └── captures/<label>/*.jpg
└── tools/
    ├── export_edgeimpulse.py
    ├── render_tts.py
    └── measure_camera_angle.md
```

### 7.1 What survives from the current code

**Keep:**
- `firmware/loadcells/` — verified working, do not touch.
- The measured values inside `bin_offsets.json` — they encode real rig geometry. They become the **seed** for `state/bin_rects.json`, converted, not the live file.
- The keystone corner values currently in the oF app → `of/hotpot-table/bin/data/keystone.json`.
- `ingredients.json`'s item list and price placeholders → restructured into `data/catalogue.json` (§8.1).
- The two `ofxFlowTools` C++17 patches and the plan to carry them as a fork submodule.
- Knowledge: projector is GLFW index 2, origin −3840,136, manual 4-point keystone survives power cycles.

**Delete outright.** This is a rewrite; deleting is the point.
- All oF C++ pricing, cart, deadband, bin-map and catalogue-loading code. It moves to Python.
- The oF keyboard mock. It moves to the staff view as real buttons.
- The in-bin weight text draw (open debt #1) — dies with the rewrite.
- `labelPlacementLogged` (open debt #2) — dies with the rewrite. **The debt is closed by deletion, not by proving the flag worked.** Do not spend time forcing it to trip.
- The "coprime" comment (open debt #4) — the justification was wrong and irrelevant.

**Open debt #5** (bins ending a session under 10g never cross the deadband, so up to ~10g per bin goes unbilled) is fixed for free in M6: at order finalisation, displayed values snap to true weights. It required a Done button, which M6 builds.

**Open debt #3** (currency placeholder) is resolved by §16.4.

---

## 8. CONFIGURATION AND STATE FILES

Hard rule: **config is committed and human-edited; state is gitignored and machine-written.** Never mix them in one file. Every machine write goes through `atomicio.write_json` — write to `<name>.tmp`, `fsync`, `os.replace`. A power cut mid-write must never produce a half-written homography.

### 8.1 `data/catalogue.json` — committed

Every item that could ever be in a bin. Not which bin it is in.

```json
{
  "schema": 3,
  "base_currency": "INR",
  "items": [
    {
      "id": "mushroom",
      "pricePer100g": 12.0,
      "names": {"en": "Shiitake mushroom", "zh": "香菇"},
      "tags": ["vegetarian", "vegan"],
      "class_name": "mushroom"
    }
  ]
}
```

`class_name` is the label string the ML model emits. Keeping it separate from `id` means retraining with different class names does not force a catalogue rewrite.

#### Hidden labels versus display names

**`id` and `class_name` are hidden. `names` is the only thing a diner ever reads.** These are two different vocabularies, not two spellings of one:

| field | who it is for | example |
|---|---|---|
| `id` | the catalogue and `bin_map.json` | `soya_chunks` |
| `class_name` | the ML model's output label | `soya_chunks` |
| `names` | the diner, on the table | `{"en": "Fish Ball", "zh": "鱼丸"}` |

The label names **a thing that is cheap to buy, photograph and train on**. The display name is **the hot pot ingredient it stands in for**. A bin trained on soya chunks can sell as a fish ball or a meat ball; `curly_noodle` and `long_noodle` are training labels for whatever noodles the menu actually lists. `names` is therefore **not a translation of `id`**, and no code may derive one from the other — no prettifier, no title-casing, no underscore stripping.

Where the two coincide in one locale, that is a coincidence of that locale and nothing more: `egg` shows as "Egg" in English and 鸡蛋 in Chinese, and the Chinese string is a translation of the *display* name, not of the label.

Two consequences, both enforced in `core/pricing.py`:

- **`Item.display_name(locale)` is the only way to get a label onto the table**, and it cannot return `id` or `class_name`. Its chain is `names[locale]` → `names["en"]`, and it raises rather than reaching past that. The bug this replaced was `names.get(locale, item.id)` in `core/main.py`, which projected the training label onto a plate the moment a locale was missing one name.
- **`Catalogue.load()` refuses any item without a non-empty `en` name.** That is what makes the chain above total. A missing translation is tolerated and degrades to English; a missing English name stops core at startup, because nothing sits below it but the hidden label.

### 8.2 `state/bin_map.json` — machine-written

```json
{"schema":3,"written":1754838400.1,"locked":true,
 "bins":[{"i":0,"item_id":"mushroom","conf":0.94,"source":"classifier"},
         {"i":1,"item_id":null,"conf":0.31,"source":"classifier"}]}
```

`item_id: null` ⇒ unresolved ⇒ renders empty ⇒ bills nothing. `locked` is true in serving mode, false while setting mode is live-updating.

### 8.3 `state/loadcell_cal.json` — machine-written

```json
{"schema":3,
 "bins":[{"i":0,"zero_counts":83422,"counts_per_gram":-214.77,"calibrated_at":1754838400.1,
          "ref_mass_g":500.0,"noise_counts_rms":18.3}]}
```

`counts_per_gram` is **signed**. Several cells are mounted inverted; the sign is *computed during calibration*, never asked of the operator. All downstream logic sees grams only.

### 8.4 `state/bin_rects.json` — machine-written

```json
{"schema":3,"camera_size":[1920,1080],"written":1754838400.1,
 "verified_at":1754838500.2,
 "bins":[{"i":0,"cam":[210,140,300,220]}]}
```
Camera space is the stored ground truth. Stage-space rects are derived at load time and never persisted — persisting a derived value invites the two copies to disagree.

`verified_at` is the timestamp of §12.6's **human** Verify answer — a person looked at the projected outlines and said they sit on the trays. It is `null` until someone has, and it is cleared by a re-solve, a rect edit, or a "No". It records *that a human answered*, and nothing about whether the geometry is right beyond their word; nothing in code may set it (§5.3's TRAP). It lives with the rects rather than with the homography because the rects are what the human was looking at. Added at M4.1.

**A consequence of storing camera rects axis-aligned, measured at M4.1 and worth recognising rather than debugging:** a homography maps a rectangle to a *quadrilateral*, so the derived stage rect is the bounding box of that quad and is a few percent larger than the tray whenever the camera is not square to the table. The dominant term is camera **rotation**, not perspective — the bounding box of a rotated rectangle grows by roughly its own size times the sine of the angle. Larger is the safe direction (I9: a cutout patch that is too small leaves a dark crescent on the food) and §13.2's cutout already adds `CUTOUT_MARGIN_MM` on top.

### 8.5 `state/homography.json` — machine-written

```json
{"schema":3,"H_cam_to_stage":[[...],[...],[...]],
 "computed_at":1754838400.1,"n_points":12,"rms_px":1.8,
 "keystone_fingerprint":"a91f...",
 "camera_size":[1920,1080],"stage_size":[1920,1080]}
```

`keystone_fingerprint` is a hash of `keystone.json`. oF reports its fingerprint in `stat`; if it differs from the one recorded here, core raises "calibration stale — keystone changed" on the staff view. This makes §5.2's warning enforceable instead of merely written down.

### 8.6 `config/system.json` — human-edited

```json
{
  "core":   {"control_port":8765,"web_port":8090,"locale":"en","conf_floor":0.65,
             "deadband_g":10.0,"settle_ms":300},
  "camera": {"device":"/dev/video0","capture":[1920,1080],"fps":30,
             "mjpeg_port":8081,"mjpeg_width":1920,"mjpeg_fps":8,
             "host_for_browser":"localhost"},
  "tracker":{"model_complexity":1,"max_hands":2,"emit_hz":60,"mirror_handedness":false},
  "classifier":{"backend":"stub","model":"models/ingredients-x86_64.eim","live_hz":2,
             "enabled":false},
  "voice":  {"backend":"stub","model":"models/keywords-x86_64.eim","threshold":0.75,
             "enabled":false},
  "of":     {"stage":[1920,1080],"monitor_index":2,"fluid_sim_scale":4,"target_fps":60,
             "field_level":1.0,"white_floor":0.45},
  "dev":    {"panel_enabled":false}
}
```

`camera.host_for_browser` is the config value that will bite on deploy day: in development the browser and the camera process are both on localhost; on the ODYSSEY, if the staff tablet is a different machine, this must be the board's LAN address. It exists as an explicit field precisely so it is visible rather than hardcoded. Note that the board has two 2.5 GbE ports and Wi-Fi, so "the LAN address" is genuinely ambiguous on this hardware — write the address of whichever interface the tablet is actually on, and see §1.4 on giving the tablet its own network rather than trusting a venue's.

**The `calibration` block no longer exists.** It held M4.3's dot-pattern
tuning (§24.1) — every number in it was a decision made from the table's
geometry rather than from a camera. Automated dot-projection calibration
was removed outright (see §24.1's note and CLAUDE.md's M4h/M4i/M4j); the
manual 4-corner tool (§12.6) needs no tuning at all.

**`classifier.enabled`** (2026-08-14, default `false`): gates `core/main.py`'s
`_classify_loop` outright — no boot pass, no periodic pass while SETTING,
regardless of `live_hz`. The model is not properly tuned yet, so a live
pass would write untrustworthy labels into the bin map rather than
leaving bins on their mock-seed placeholders. Does not touch the Setup
tab's manual dataset capture (`_handle_capture`), which never calls
`_classify_pass` — collecting training data is the reason to run with an
untuned model, not a reason to block it. Flip to `true` once the model is
retrained and worth trusting live.

`of.field_level` and `of.white_floor` are the two I9 knobs, and both are **measured on the rig, not chosen** (§6.6, §13.2). They are config rather than constants specifically so they can be swept without a rebuild. `field_level` is additionally mirrored into `state/camera_settings.json` at startup, because it belongs to the dataset's provenance as much as exposure does — config says what the rig is set to, that file says what the training images were taken under.

**`camera.windows_device_index`** (optional, not in the JSON above): read via `config.get(cfg, "camera.windows_device_index", 0)`, so its absence is not an error. It exists only for `camera/capture.py`'s `WindowsCapture` — a dev-machine capture backend for a USB webcam over DirectShow, picked automatically by `sys.platform` when `camera/main.py` runs on Windows. Not a doc build item and not part of the deploy schema: the ODYSSEY rig is always Linux, so this key is never read there. `camera.device` keeps its Linux/`V4L2Capture` meaning unchanged.

---

## 9. CORE — DOMAIN MODEL

### 9.1 The finite state machine

```
BOOT
 └─► UNCALIBRATED ──(calibration complete)──► IDLE
IDLE ──(hand present OR staff "start")──► SELECTING
SELECTING ──(dwell "done" OR keyword "done")──► BROTH
BROTH ──(broth chosen)──► SPICE
SPICE ──(spice chosen)──► RECAP
RECAP ──(dwell "confirm")──► CHECKOUT
CHECKOUT ──(receipt fetched OR timeout 90s)──► IDLE   [re-baseline, clear cart]
any ──(enter setting, cart not active)──► SETTING
SETTING ──(exit setting)──► IDLE   [refresh weights, re-baseline, lock bin map]
```

The two modes are **SERVING** (the table is billing) and **SETTING** (the table is being changed). `SETTING` is the FSM state; everything else is SERVING. The names say what the table is *doing*, not who is standing at it — staff are present in both, and a diner can walk up during either. Note that `staff "start"` above is a *person* pressing Start on the tablet and has nothing to do with the mode; that is a collision these names remove rather than create.

Rules that are not negotiable:

- **Setting mode is refused while a cart is active.** One wrong keypress must not destroy a diner's order. The staff view shows *why* it is refused and offers "cancel the order first" — so the refusal must carry a plain-language reason, not just a false.
- **"Cart is active" is the deadbanded shown grams, not raw removed grams.** Raw removed grams moves with load-cell noise, which would hold the refusal true permanently and make setting mode unreachable. It is also what the diner can see: refusing on something visible is explicable to an operator, refusing on invisible noise is not. The accepted cost is that a sub-deadband pick survives entry and is discarded by exit's re-baseline.
- **Cancel-order re-baselines** (`startWeightGrams[i] = binWeightGrams[i]`), clears the cart, and stays in serving mode. Nothing goes to zero (I6).
- One shared function `reset_session()` is called from three places: cancel, checkout completion, and setting-mode exit.
- **Setting-mode exit does three things, IN THIS ORDER: refresh every bin's weight from the scale, then `reset_session()`, then lock the bin map.** All three live inside the exit transition so no caller can do two of them and forget the third.
  - **The refresh is not optional and omitting it mis-bills silently.** Billing is disabled for the whole of setting mode, so at exit `live_g` still holds the weights from when the mode was *entered*, and `reset_session()` does `start_g[i] = live_g[i]`. Swap a full tray for an empty one during setting mode — which is the entire point of the mode — and without the refresh, exit baselines `start_g` to the tray that left. The difference becomes removed grams and **the next diner is billed for the swap.**
  - A bin the scale cannot weigh (uncalibrated, or a dead XIAO) keeps its placeholder weight; `reset_session()` still re-baselines it where it stands.
- **BOOT always goes to UNCALIBRATED if `homography.json` or `bin_rects.json` is missing.** In UNCALIBRATED, serving mode is unreachable, oF shows the `uncalibrated` overlay, and the staff view opens on the calibration wizard. This is the first-boot path and it must work on a fresh clone with an empty `state/`.
  - "Missing" means **either file absent, unparsable, or incomplete** — seven rects and a hole counts, because the eighth bin would otherwise render from a fallback nobody chose. A homography that loads but cannot be inverted counts too: "the file is there but nonsense" has to land in the same place as "the file is not there", or a fresh clone crashes at boot instead of showing the wizard (M4.6).
  - **"Serving is unreachable" is a predicate, `fsm.serving`, not `state is not SETTING`.** The scale reaching the cart is gated on it, so a state added later cannot start billing by omission. A table that does not know which tray is which must not weigh food out of one and charge for it.
  - **Setting mode stays reachable from UNCALIBRATED, and must** — calibration is a setting-mode activity, so blocking entry would make the state unescapable.
  - **Setting-mode exit returns to UNCALIBRATED, not IDLE, when the geometry still is not there.** The diagram above writes that edge as SETTING → IDLE, which is right for the ordinary case and wrong for the first-boot one: the operator is *in* setting mode while calibrating, and an exit that always landed on IDLE would open a table with no geometry. The check is re-asked at exit rather than remembered from boot, because the whole point of the mode being left is that the operator may have just fixed it. (M4.6.)

### 9.2 Pricing (restating I4/I5 as code shape)

```python
removed_g   = max(0.0, start_g[i] - live_g[i])
price[i]    = (removed_g / 100.0) * catalogue[bin_map[i]].price_per_100g
total       = sum(price[i] for i in range(8) if bin_map[i] is not None)
```

Display deadband, separate from the above and touching nothing above:

```python
if abs(removed_g - shown_g[i]) >= DEADBAND_G:
    shown_g[i] = removed_g          # SNAP to truth, not increment
```

At order finalisation: `shown_g[i] = removed_g` for all i, unconditionally. That single line is the fix for open debt #5.

### 9.3 Unresolved bins

A bin is unresolved if `bin_map[i].item_id is None` or `conf < conf_floor`. Unresolved bins:
- render with no label and a muted plate,
- contribute 0.00 to the total no matter how much mass leaves them,
- are listed loudly in the staff view,
- block setting-mode exit with a confirm dialog ("2 bins unresolved — items taken from them will not be charged. Exit anyway?").

### 9.4 Hover and dwell

Core receives stage-space cursors from the tracker (§4.6) and hit-tests them against stage-space bin rects and widget rects.

- Only `role == "pointer"` hands are hit-tested. Ambient hands are ignored entirely for selection.
- Dwell: a widget accumulates dwell time while the pointer is continuously inside it. Leaving resets to 0 after a 150ms grace (so a jittery frame does not reset a nearly-complete dwell).
- Default dwell to fire: **1200ms**. Configurable. This is long enough not to misfire and short enough not to feel broken.
- Core sends `dwell` as a 0..1 fraction in `state.widgets[].dwell` so oF can draw a filling ring. oF does not time anything.
- Hover on a *bin* is feedback only. It never bills. Billing is weight, always (I4).

### 9.5 The serial thread

One thread inside core. Blocking `readline()` on the serial port at ~78Hz. It writes the latest parsed 8-tuple into a single slot guarded by a `threading.Lock`, plus a timestamp. The main loop reads the slot. There is no queue — a queue would let the main loop fall behind and then process stale weights.

```python
class ScaleReader(threading.Thread):
    def run(self):
        while not self._stop.is_set():
            line = self.port.readline()
            counts = parse(line)          # returns None on junk
            if counts is None: continue
            with self._lock:
                self._latest = (counts, time.time())
```

Main-loop read: if `time.time() - ts > 0.5`, the XIAO is gone → all bins report stale → staff view shows a red serial pip → the table shows a fault overlay. Do not silently bill from a frozen reading.

Smoothing: a median-of-5 on counts before gram conversion. Median rather than mean because a single bad HX711 read is an outlier, not noise, and a mean would smear it across five samples.

Settle detection for the classifier trigger: a bin has settled when its gram value has stayed within ±2g for `settle_ms` (default 300ms).

### 9.6 Load-cell calibration maths

Two-point, done entirely from the staff view (§12.4).

```
zero_counts     = median(counts while bin empty, 2s window)
counts_per_gram = (median(counts with ref mass) - zero_counts) / ref_mass_g
grams[i]        = (counts[i] - zero_counts[i]) / counts_per_gram[i]
```

`counts_per_gram` comes out negative for inverted cells and everything downstream just works. **The operator is never asked about sign or orientation.** The staff view shows only: "Bin 3 empty? → Tare" then "Place a known weight → enter grams → Calibrate."

Sanity check that can actually fail: after calibration, if `abs(counts_per_gram) < 10` the cell is probably not connected or the reference mass was too light. Refuse and say so.

### 9.7 The order database — `state/orders.sqlite3`

```sql
CREATE TABLE orders(
  id INTEGER PRIMARY KEY,
  code TEXT NOT NULL,             -- short human code, e.g. "A17"
  created_at REAL NOT NULL,
  status TEXT NOT NULL,           -- new | cooking | served | void
  broth TEXT, spice INTEGER,
  locale TEXT, currency TEXT,
  total REAL NOT NULL
);
CREATE TABLE order_lines(
  order_id INTEGER REFERENCES orders(id),
  bin INTEGER, item_id TEXT, grams REAL, price_per_100g REAL, line_total REAL
);
```

SQLite because it is in the standard library, is a single file, survives a power cut, and gives the staff view real restaurant-software features (today's orders, revenue, top items) for almost no code.

---

## 10. `run.py` — SINGLE-COMMAND START AND STOP

Requirement: everything starts with one call and dies with one call.

### 10.1 Why a Python launcher and not systemd

systemd is the production-correct answer on Linux but it does not exist on the Windows development machine, and having two different launch paths for dev and deploy is exactly how "works on my machine" happens. A small Python supervisor runs identically on both. For the ODYSSEY, a systemd unit is provided that does nothing but `ExecStart=/usr/bin/python3 /opt/hotpot/run.py` — one launch path, optionally wrapped.

### 10.2 Behaviour

```
python run.py                 # start everything, stream merged logs, Ctrl-C stops all
python run.py --stop          # stop a detached instance
python run.py --only core,of  # start a subset (development)
python run.py --no-restart    # disable auto-restart (debugging a crash)
```

Implementation requirements:

- Each child is launched in its **own process group** (`start_new_session=True` on POSIX, `CREATE_NEW_PROCESS_GROUP` on Windows) so that killing the group kills grandchildren too. An orphaned process holding `/dev/video0` or a TCP port is the single most annoying failure mode in a system like this.
- A pidfile at `state/run.pid` holding the launcher pid and each child's pid.
- Each child prints `HOTPOT-READY <name>` to stdout once it is genuinely serving. The launcher waits for readiness before starting the next tier.
- The launcher tails every child's stdout/stderr, prefixes each line with the process name and a colour, and writes to `logs/hotpot-<date>.log` with rotation.
- On `SIGINT`/`SIGTERM`: send `SIGTERM` to every group, wait 5s, `SIGKILL` survivors, remove the pidfile. Report which processes needed the kill — needing it is a bug to fix later.

### 10.3 Start tiers

```
tier 1: camera            (creates shm, serves MJPEG)
tier 2: core              (binds control port, opens serial, serves staff view)
tier 3: tracker, classifier, voice, of   (all clients, all reconnecting)
```

Because every client reconnects with backoff (§19), tier order is an optimisation for clean logs, not a correctness requirement. Do not add ordering dependencies that make it one.

### 10.4 CPU affinity — using the hardware fully

**Now finalised against the J4125: 4 cores, 4 threads, no SMT (§1.4).** The plan below was written before the board was known and happens to fit it exactly — four cores, four assignments. "Exactly" is the important word: there is no spare core, so the details of what is *not* pinned matter as much as what is.

On Linux, after all children are up, the launcher pins processes with `os.sched_setaffinity`:

| Core | Process | Notes |
|---|---|---|
| 0 | `of` | **Dedicated, exclusive.** Everything else is excluded from it. This is the whole reason for the process split. |
| 1 | `tracker` | MediaPipe inference, single-threaded by configuration so it cannot spill. |
| 2 | `classifier`, `voice` | They never run hot at the same time — classifier is setting-mode, voice is serving-mode. |
| 3 | `camera`, `core` | Plus the launcher, plus everything the OS does. |

Because there is no fifth core, three rules follow that were optional on a bigger machine and are not here:

- **The launcher does not pin itself.** It stays on the default mask, or explicitly on core 3. A supervisor that has claimed a core is a supervisor competing with the thing it supervises.
- **Set `OMP_NUM_THREADS=1` and the equivalent TFLite/OpenCV thread counts to 1** for `tracker` and `classifier` before spawning them. These libraries default to spawning one worker per visible core. Four workers inside a one-core affinity mask is strictly worse than one worker — it is the same work plus scheduler thrash — and it is invisible until you look for it.
- **Interrupts still land on core 0.** USB completion for the camera in particular. Pinning `of` exclusively excludes *processes*, not IRQs. If M8 shows frame-time spikes on the table that correlate with camera activity, move USB IRQ affinity off core 0 (`/proc/irq/*/smp_affinity`) before touching anything in the renderer. Do not reach for this pre-emptively; know it exists so it is a ten-minute fix rather than a lost day.

If the machine has fewer than 4 cores, log a warning and skip pinning entirely rather than pinning badly. That branch is now unreachable on the deploy target but stays for the development machines.

---

## 11. TRACKER

### 11.1 Pipeline

```
attach shm → read latest frame → downsample to model input →
MediaPipe Hands → landmarks → pick a cursor point →
camera→stage homography → role assignment → UDP to of and core
```

### 11.2 Cursor point

Use the **middle-finger MCP joint (landmark 9)**, not the wrist and not the index tip. The wrist sits far from where a person feels their hand is; the index tip moves wildly as fingers flex and while holding tongs. Landmark 9 is the palm centre and is stable whether the hand is open, closed, or gripping.

`model_complexity`: **start at 0 (lite), probe upward.** This reverses the previous instruction, which said to start at 1 on the grounds that "the reComputer x86 is far stronger than the Pi 4B the old 8-FPS figure came from." Now that the board is known (§1.4) that reasoning does not survive: a J4125 is roughly 2× a Pi 4B in both single- and multi-core terms, not an order of magnitude, and **it has no AVX2**, which is precisely the instruction set MediaPipe's x86 inference leans on. The honest expectation is that complexity 1 does not hold 25 fps on this board.

So: start at 0, measure for 5 seconds, and if the measured rate is above 45 fps try 1 and keep it only if it stays above 25. Auto-probe rather than hardcode, and log which rung it settled on. Probing upward from a rung that works is safe; probing downward from one that does not means the first seconds of every run are janky.

**VERIFY at M0, before any tracker work (§1.4b):** run one MediaPipe Hands inference on the board and confirm it neither crashes with `SIGILL` nor silently falls back to a path that cannot hold 25 fps at complexity 0. An illegal-instruction crash on demo day from an AVX2-only wheel is a foreseeable failure with a cheap check. If the stock `mediapipe` wheel is AVX2-only, the fallback is building it for this target or dropping to a plain TFLite hand model — that is a hardware-driven porting task to discover in M0, not in M5.

### 11.3 Two hands, two roles — pointer and ambient

Requirement: the right hand selects; the left hand holds the bowl and may play with the fluid but must never select anything.

MediaPipe reports handedness, but handedness from an overhead camera with a possibly-mirrored image is not reliable enough to bet the interaction on. Therefore:

**Role is assigned to a tracked hand, not recomputed per frame.**

```
1. Track hands across frames by nearest-neighbour on the cursor point
   (gate: 150 px in stage space between frames). Assign each a stable id.
2. When a hand first appears:
     - if no pointer currently exists          → role = pointer
     - else if MediaPipe says "Right"          → role = pointer, demote the other
     - else                                    → role = ambient
3. Role is LOCKED for the lifetime of that tracked id. It never flips mid-gesture.
4. When the pointer hand disappears for >500ms, its role is released.
   The remaining ambient hand is promoted to pointer only after a further 500ms.
```

Config `tracker.mirror_handedness` flips MediaPipe's label; the staff view has a "swap hands" button that toggles it live, because the correct value is a property of the physical mounting and is fastest to determine by trying it.

Rationale for step 2's fallback: with one hand on the table, that hand is the pointer regardless of which hand it is. A left-handed diner alone at the table must not be locked out.

### 11.4 What ambient hands do

They are still sent (`role:"ambient"`) so oF can inject fluid forces at their position. oF draws **no cursor and no dwell ring** for them. Core **discards them entirely** before hit-testing. The isolation is at the consumer, in both consumers, so a bug in one cannot leak selections.

### 11.5 Bench tests still outstanding

Both were flagged in Stage 1 and are still undone. They belong in M5.

1. **Bowl-hand false triggering.** A bowl held over a bin may present as a hand-shaped blob. Test with the real bowl.
2. **Tongs and palm confidence.** MediaPipe's palm detector may lose confidence when the hand grips tongs. Test with the real tongs, at the real height, under the real projector light.

---

## 12. STAFF VIEW

The staff view is not a debug page. It is the calibration surface, the diagnostics surface, the dataset-capture tool, and the restaurant-management console. It must be usable by an untrained person and must also, on demand, expose everything a developer needs.

### 12.1 Design principles

- **Dark UI.** The environment is dim; a white page is a flashlight in the operator's face. **This is the operator's screen, not the projected field** — it is not a contradiction of I9, which governs light landing on the table. The two surfaces have opposite jobs: the tablet is read by a human eye in a dim room, the table is read by a camera whose only controlled light is the field itself.
- **Touch first.** Assume a tablet. Minimum touch target 44×44 CSS px. No hover-only affordances.
- **One primary action per screen.** An untrained operator should never have to choose between two similarly-weighted buttons.
- **State is always visible.** Mode, order total, and the six process pips are in a header that never scrolls away.
- **Plain language, no jargon in the operator-facing layer.** "Bin 3 is empty" not "bin 3 unresolved, conf 0.31 < floor 0.65". The second sentence belongs in the developer panel.
- Served by core, plain HTML/CSS/vanilla JS as a single-page app. **No build step.** A build step means the deploy machine needs Node, and it will not have it at 2am before judging.

### 12.2 Layout

```
┌──────────────────────────────────────────────────────────────┐
│ 〔logo〕[Live][Bins][Setup][Capture] ¥41.20 Serving(━●) [Dev] │  header, fixed
├──────────────────────────────────────────────────────────────┤
│                                                              │
│                      (tab content)                           │
│                                                              │
├──────────────────────────────────────────────────────────────┤
│  Not serving — the table is not charging anyone while        │
│  the switch is off.                  [ Cancel order ]        │  action bar, fixed
└──────────────────────────────────────────────────────────────┘
```

The six pips are `camera · tracker · classifier · voice · core · table`, each green/amber/red, each tappable for detail. `table` means oF. Colour alone is never the only signal — each pip also carries a one-letter code, because kitchen lighting and colour-blindness both exist. **They ride the Developer toggle** and are not in the operator's header, which is why the mockup above has no room for them: an operator cannot act on "tracker is amber", and six coloured dots in the corner of every screen train them to ignore colour in the one UI where colour carries the mode.

**The mode lives in the header — not in the action bar**, which is where the mockup above puts it. Correcting the mockup, after seeing it on a tablet: a status indicator at the top-left and the control that changes it at the bottom-left read as two unrelated things, and nothing tells you which control drives the state you are looking at. State and its control go together, and keeping a consequential toggle out of the bottom thumb-rest also makes it harder to mis-tap.

**It is ONE switch, labelled `Serving`, and OFF IS SETTING MODE.** This corrects the mockup a second time, and supersedes both earlier designs: the chip + `ENTER SETTING MODE` button in the mockup above, and the two-half `Setting|Serving` segmented switch that replaced it. The chip and button said the same word twice, side by side, once they were adjacent. The segmented switch then made the operator read two words and work out which half was lit before knowing what the table was doing. A switch answers a question, and the question has one noun in it: **is the table serving, yes or no.**

- **Off is the ordinary greyed-out off**, the shape every tablet switch already has, so nothing about the control has to be learned. The cost is named rather than hidden: the table's setting-mode banner is amber (I8) and this corner of the tablet is no longer amber with it. What says "setting" here instead is the knob's position, the dead track, and the action hint below in words.
- **The operator-facing layer names the CONTROL, never the mode.** Every hint and refusal reads `Turn Serving off to …` — including core's own `NOT_IN_SETTING_MSG`, shown verbatim on the tablet. The word "setting" appears nowhere in the header, so "enter setting mode" would send an operator hunting for a control that does not exist. `setting` remains the FSM state, the wire value, and this document's word for the mode; it is not the operator's.
- **§12.1's "one primary action per screen" argued for a button, and the mis-tap worry behind it is real** — so the two things that make a switch safe are unchanged and must stay: turning Serving off is **refused with a reason** while an order is live (§9.1), and turning it back on **re-baselines every bin from the scale before `reset_session()`** (§9.1's trap).
- **When refused, the switch stays tappable and explains.** It is never disabled silently. Tapping with an active cart shows §9.1's reason verbatim, plus a "Cancel the order first" action wired to `Cancel order` — that pairing is what §9.1 requires.
- The mode message carries `cart_active` alongside the mode, so the header can pre-warn beside the switch before a tap is made rather than after a round trip.
- Before the join seed arrives the mode is genuinely unknown, and off is now a real position rather than a blank one — so that state **drops the knob entirely** and sinks the track below the off grey. A switch drawn in a position it does not know is a lie.

The **action bar** stays fixed to the bottom, above the developer panel, on every tab, and holds what is **order-scoped** rather than system-scoped: `Cancel order`, which confirms before it fires because it re-baselines. That split — system state in the header, order actions in the bar — is why the toggle moved and `Cancel order` did not.

### 12.3 Tab: Live

- The MJPEG feed at natural size, CSS-scaled to fit, with an HTML `<canvas>` overlay sized to `naturalWidth × naturalHeight` and CSS-scaled identically.
- Overlay draws: the 8 bin rects, each labelled with the item name, live grams, and — when the classifier is running — the label and confidence.
- A hand marker for each tracked hand, with the pointer drawn differently from ambient.
- Toggle chips: `rects · labels · weights · hands · dots`.
- **As built (M4l): once the table's corners are confirmed (§12.6), this tab shows the same flattened, top-down rectangle the Setup tab's resting view does**, not the raw feed — the `<img>` is hidden and the canvas draws `drawRectifiedPreview` instead, reusing the Setup tab's own geometry helper and confirmed-corners state rather than a second implementation, so the two tabs can never disagree about what "flattened" looks like. Before corners are confirmed, this tab is unchanged (raw feed, canvas transparent).

### 12.4 Tab: Bins

Eight cards. Each card, top to bottom:

```
┌────────────────────────────┐
│ Bin 3        香菇 Shiitake │
│                            │
│        418 g               │   ← large, ~44px
│        ¥12.00 / 100g       │
│                            │
│  ●●●●●●○○  stable          │   ← noise indicator
│                            │
│  [ Tare ]    [ Calibrate ] │
└────────────────────────────┘
```

**Tare and Calibrate both require setting mode** (§9.1). The flow below asks the operator to empty a bin and then place a reference mass in it; in serving mode both of those are ordinary picks and would be charged for. The mode is what makes them safe — it replaced an earlier per-bin freeze that existed only because no mode-wide state had been built yet.

**Both buttons are disabled outside setting mode, and say why** — on the card permanently, and in a `title` for hover. They are never left live to fail at the end. The first version refused only when the request reached core, which meant the operator had already emptied the bin, opened the wizard and tapped Confirm before being told: the answer arrived after all the physical work, at the last possible moment. Core still refuses independently — the rule about what is safe to do to a bin belongs on the side that owns the cart, and a stale page must not be able to tare a serving table — but no operator should ever see that refusal.

**Tare has a bulk button; Calibrate cannot have one.** Setting the table means eight empty bins at once, and taring them one at a time is eight trips through a wizard whose entire content is "the bin is empty". `Tare all 8 bins` does every bin from **one** capture window — `scale.capture()` already reduces all eight channels over the same window — so it takes 2 s rather than 8 × 2 s, and every bin's zero comes from the same instant, which matters more than the speed: a drift affecting the whole board lands on all of them identically instead of being smeared across sixteen seconds. Each bin still gets its own zero out of that window; a shared one would mis-weigh seven bins. Calibrate has no bulk form because each bin needs its own reference mass physically placed in it, one at a time.

Calibration flow, one screen at a time, no branching:

1. Tap **Tare** → "Make sure bin 3 is empty" → **Confirm** → 2s capture → "Done. Bin 3 reads 0 g."
2. Tap **Calibrate** → "Place a known weight in bin 3" → numeric text field, prefilled 500 g, overtype with the physical keyboard (Enter submits) → **Confirm** → 2s capture → "Done. Bin 3 reads 500 g."
3. If the result fails the sanity check (§9.6), show "That didn't work — check the wiring for bin 3, or use a heavier weight" and do not save.

The operator is never shown or asked about counts, sign, multipliers, or orientation.

### 12.5 Tab: Orders

Restaurant-management surface. This is what makes the entry look like a product rather than a demo.

- **Queue:** cards for today's orders, newest first, `code · time · total · status`. Status advances `new → cooking → served` with one tap. Void requires confirmation.
- **Order detail:** the itemised lines, weights, prices, broth, spice.
- **Today:** order count, gross revenue, average order value, top 5 items by weight sold. Plain numbers and one bar list — no charting library.
- **Low stock:** bins whose current weight is below a per-item threshold, surfaced as a list and mirrored to the table as a pulsing plate.

### 12.6 Tab: Setup

- **Set the table corners** — the only calibration path (§24.1's dot-projection wizard was removed outright; it needed a dark, room-light-free rig this project never achieved). **"Set table corners" hides itself once tapped**, replaced by **Cancel** and **Confirm** — a persistent draggable quad, not a click sequence, with 4 fixed-role handles (near-left/near-right/far-right/far-left, never inferred from where a drag ends up, immune to the camera's mount angle) and a ~4x magnifier while a handle is held. Cancel discards the drag with nothing sent to core; Confirm sends all 4 points and `GeometryStore.fit_from_corners` solves the homography from those correspondences directly — no pattern to project, no detector, no dark room. **The feed shown while dragging is the camera's own real, unmodified orientation — there is no rotate/display-transform control.** The operator reads physical near/far/left/right off the real table itself, the same principle the fixed roles already rely on. **Once corners are confirmed, both this tab's resting view and the Live tab (§12.3) switch to a flattened, top-down rectangle** (`drawRectifiedPreview`, a display-only affine warp of the 4 confirmed points — independent of the real projective `H_cam→stage`; nothing about the homography or `set_rects` changes because of it).
- **Adjust bin rectangles** — drag the 8 rects on the live feed. Drag inside to move, drag the corner handle to resize. Undo. Save is explicit. Snap-to-grid was optional and is **not built** — nothing about a hand-dragged tray position wants quantising, and it would have been a setting to explain.
- **Verify** — asks the operator: *"Are the outlines sitting on the trays?"* with **Yes** / **No**. **TRAP:** this human confirmation is the only verification of the homography's direction that can actually fail. Do not replace it with a reprojection check.

  **As built (M4.4), there is nothing to switch on for this step and that is deliberate.** The outlines are already on the table every frame: core sends the derived stage rects in `state.bins[].rect` and oF draws each plate ring and each light-pass cutout on them (falling back to `TableGeometry.h`'s CAD layout when core has none). So "Verify" is two buttons and a recorded answer — `verified_at` in §8.4 — and nothing more. A separate "projection mode" would have been a second rendering path whose agreement with the real one nobody could check.
- Everything on this tab requires **setting mode**, the same rule §12.4's Tare and Calibrate follow and for the same class of reason: the solve inverts the field to black for several seconds, and moving a rect moves the light-pass cutout off the tray. Refused server-side too, not only greyed out on the tablet.
- Swap hands (§11.3), locale, broth and spice options, deadband, dwell time, confidence floor — **not built at M4**; each belongs to the milestone that gives it something to change (M5 for swap hands and dwell, M6 for broth and spice).
- **Developer panel toggle** — off by default (§12.8). **Still on the top bar, not here** (M1.5 put it there because Setup did not exist). Moving it is a one-line change and was left alone at M4 rather than bundled into a milestone about geometry.

### 12.7 Tab: Capture — dataset collection

This exists so that training data can be gathered from the real rig under the real lighting, which is the only data that matters.

- Live view of the 8 bin crops, side by side, at the resolution the model will see.
- Each crop has a label selector defaulting to the current bin-map item.
- **Capture all** — saves 8 crops with their assigned labels in one tap.
- **Burst** — N frames, a fixed interval apart (default 10 frames, 2s apart), so the operator can nudge the tray between frames and get pose variation. Frames and interval are two separate fields, not a frame count plus a total period — a total period made raising the frame count silently shrink every gap, backwards from what an operator reaching for more frames usually wants (more time per gap, not less). **A live counter and countdown** — "Shot 4 of 10, next photo in 2s" — run off the classifier's own per-shot `capture_progress` message (§4.7), reset on every shot rather than a client-side timer trying to predict shot timing on its own.
- Session counter per label, so the operator can see they have 40 mushrooms and 6 prawns and go collect more prawns.
- Files: `datasets/captures/<label>/<unixms>_bin<i>.jpg`, plus a sidecar `.json` with bin index, rect, timestamp, and the exposure/WB **and `field_level`** values from `state/camera_settings.json`.
- **Export for Edge Impulse** — runs `tools/export_edgeimpulse.py`, producing a folder-per-label tree ready for `edge-impulse-uploader`.

Deliberate design note, **revised under I9**: an earlier session concluded "do not vary the lighting and do not measure the illuminant," on the reasoning that the dataset spans varied conditions naturally across sessions so the model learns to ignore illumination, and that illuminant measurement only matters for a single-illuminant dataset — "which this is not."

That premise no longer holds, or at least not in the form it was written. The projected field is the dominant illuminant and the only one this system controls exactly, so this is close to a single-illuminant dataset. **It is not strictly one: the dark room was never achieved (§24.1), so uncontrolled room light is a second illuminant on every capture.** The conclusions below were drawn assuming the strict case, and the first still holds regardless; the second is weaker than it reads, and is flagged here rather than silently rewritten:

- **Do not vary the lighting** — still right, and now for a stronger reason. There is nothing to vary; the field is a constant.
- **Do not measure the illuminant** — still right, but not because measurement is unnecessary. It is unnecessary because the illuminant is *known*: it is a flat white patch at a recorded `field_level`. Record it (above); do not go photometering it.
- **New and load-bearing:** capture must run with the bin patches lit exactly as serving mode lights them. A capture session taken with a different `field_level`, with the fluid or the staff grid bleeding into a cutout, or during calibration's black-field inversion, produces a training set the live rig will never reproduce. The Capture tab must therefore drive the same bin-patch path as serving mode, not its own.

**How that is satisfied as built (M4.7), because "must drive the same path" is a rule about what the code does *not* contain:**

- **The tab has no lighting control of any kind, and neither does core's capture handler.** There is nothing to keep in sync, so nothing can drift out of sync. The crops the operator previews are drawn from the *same* live `<img>` the Live and Setup tabs show, at the bin's own camera-space rect — same image, same rectangle, no second endpoint that could disagree.
- **There is no longer any moment the field differs from serving mode during setup.** Dot calibration's black-field inversion (I9) was the one exception, and it is gone along with the wizard that needed it — calibration is now the manual corner tool (§12.6), which reads the already-lit feed like every other tab. The refusal that used to guard a capture against overlapping a solve has been removed with it; there is nothing left for it to guard against.
- **Setting mode is required** — not for the lighting (§14.5: "the field and the bin patches are identical to serving mode" in setting mode) but because the operator is reaching over trays, which in serving mode is a pick and would bill. Same reason §12.4's Tare and Calibrate need it.
- **The rects come from the geometry store, not from the tablet**, so an un-saved drag can never reach the dataset.
- The label selector defaults to the bin-map item's **`class_name`**, not its display name. §8.1's hidden-label rule runs the *other* way here than it does on the table: a training folder called "Fish Ball" is a folder the model can never emit a label for.
- The session counter is read off the filesystem, not held in memory — an operator who restarts core mid-collection must not see it reset to zero.
- `tools/export_edgeimpulse.py` exists for three reasons beyond rearranging a tree that is already folder-per-label: the sidecars must not be uploaded, filenames must survive being flattened (two bins captured in the same millisecond differ only by their `_bin<i>` suffix), and somebody has to print how thin the thin classes are. It also counts **distinct days**, separately from images: 600 photographs of one tray under one arrangement of the light is one session's worth of information however many files it is.

### 12.8 Developer panel

Hidden behind a toggle in Setup, off by default, persisted in `localStorage`. When on, a collapsible strip appears at the bottom of every tab:

- Per-process: PID, uptime, restart count, last heartbeat age, CPU%, **pinned core**.
- **Machine: package temperature, current core clock, and a throttle flag.** Not decoration. §1.4 explains why: this workload saturates four cores and the iGPU beside a heat source, and a throttled J4125 loses clock on all four cores at once. That presents as the fluid degrading and the tracker slowing *simultaneously*, which looks exactly like a software regression and will be debugged as one for hours. Read `/sys/class/thermal/thermal_zone*/temp` and the `package_throttle_count` under `/sys/devices/system/cpu/cpu0/thermal_throttle/`. Surface the flag in red — it is the one telemetry line that turns a mystery into a five-second diagnosis.
- Camera: capture resolution, actual FPS, frame_id, shm slot in use, dropped frames.
- **Camera controls** — every exposure/white-balance/focus/brightness/contrast/saturation/gain/sharpness/hue/backlight-compensation knob the open camera backend exposes (`camera/mjpeg.py`'s `GET /controls.json`/`POST /control`, hit directly from the staff view the same way `/info.json` already is — camera owns this state, core does not proxy it). A control with an auto mode gets an Auto/Manual toggle; Manual unlocks its slider and pins the value, written to `state/camera_settings.json` (the original three fields plus an additive `controls` map for the rest) so it survives a restart the same way §6.6's sweep-and-freeze already does. A "Reset to camera defaults" button undoes a sweep gone wrong: auto-capable controls (white balance/exposure/focus) go back to Auto, and manual-only ones return to `ControlSpec.default` — the real device-reported default on V4L2, a boot-time snapshot (read before this process touched anything) on Windows, since DirectShow has no default-query API; a control with neither known is left alone rather than guessed at. This is the tool for actually finding "the best picture," not just reading numbers — the six read-only stats above answer "what is the camera doing," this answers "make it do something else."
- Tracker: inference ms, hands tracked, ids and roles, emit rate.
- oF: FPS, GPU ms, fluid sim resolution, keystone fingerprint.
- Core: loop rate, serial rate, raw counts per bin next to grams, current FSM state.
- Homography matrix, RMS error, point count.
- Live log tail with a level filter.
- **Mock controls** — the keyboard mock from Stage 2, reborn: pick/put-back buttons per bin with the `{45,6,120,3,25,80}` g size cycle. This is how M1 is demoed before load cells are wired, and it stays forever as a test harness.

### 12.9 Typography — staff view

| Role | Size | Weight |
|---|---|---|
| Page/tab titles | 20px | 500 |
| Body, labels | 16px | 400 |
| Secondary, units, hints | 14px | 400 |
| Large numerics (grams, total) | 44px | 500, tabular-nums |
| Developer panel | 13px | 400, monospace |

Font stack: `Inter, "Noto Sans SC", system-ui, sans-serif`. **`tabular-nums` on every live-updating number** — without it, digits change width as they update and the whole row jitters, which reads as instability.

---

## 13. openFRAMEWORKS RENDERER

### 13.1 Responsibilities

Receive state, tween it, draw it, warp it, play sounds. Nothing else (I2).

### 13.2 FBO stack

Two FBOs and two full-stage passes, warped once at the end. The order is what enforces I9:

```
1. fluidFBO    — the fluid simulation, upscaled to stage size
2. uiFBO       — labels, prices, widgets, cursor, overlays, bin outlines
   ─────────────────────────────────────────────────────────────
3. FLOOR LIFT  — applied to the composite of 1+2, per pixel:
                     out = k + (1 - k) * in          (k = white_floor)
4. LIGHT PASS  — flat pure-white patches stamped over every tray cutout,
                 at full field level, after everything else
   ─────────────────────────────────────────────────────────────
   → keystone warp → screen
```

**Step 4 is last on purpose, and that is the entire safety property.** I9's rule is not "remember not to draw into a cutout" — it is "you cannot." Any layer that misbehaves, any overlay added later, any uncommented test pattern, any fluid splash: all of it is overwritten by the light pass before the frame reaches the projector. A rule enforced by drawing order cannot be forgotten by a future change. This has already been proven necessary — the Stage 1a test pattern's grid and diagonals crossed four of the eight cutouts, and were only survivable while black rects were drawn after them to absorb the damage.

**Step 3, the floor lift**, is what makes "bright and vibrant" and "trackable" compatible. Rather than restricting every palette to pale tints, the styles keep their full hue and chroma relationships and the composite is lifted toward white by a constant:

- `white_floor` (`k`) is a config value in `config/system.json`, **default 0.45**, meaning no channel of any pixel outside a cutout ever falls below 45% of full output.
- The floor is on the **minimum RGB channel, not on luminance** — and that distinction is the point. A fully saturated red has a relative luminance of at most 0.21, so a luminance floor of any useful height would ban saturated colour outright and force the whole table into pastels. A per-channel floor guarantees every channel carries light — so skin still reads as skin to MediaPipe — while leaving the chroma *between* channels free. Vivid colour above a guaranteed white base.
- It is unconditional and per-frame. There is no style exemption and no "only when a hand is near" optimisation; intermittent hand tracking is a worse failure than a compromised palette.
- **VERIFY on the rig at M5, with the tracker running:** sweep `k` downward from 0.45 and find where hand detection starts dropping frames over the darkest part of the field. Set it with margin above that. This is a measured number, not a chosen one — 0.45 is a starting point.

**VERIFY, and this has bitten before:** `ofxFlowTools` leaves the blend mode as `OF_BLENDMODE_ADD`. Call `ofEnableAlphaBlending()` explicitly before drawing the UI layer, every frame. Do not assume the state you left it in.

**The scrim layer is gone.** It had two jobs and both are obsolete: black rects over cutouts are now the light pass, inverted; and dark plates behind text are unnecessary on a light field, where contrast comes from dark ink and heavy stroke weight instead (§13.4).

### 13.3 Tweening

oF holds, per bin: displayed grams, displayed price, highlight colour, plate scale. Each is tweened toward the target from `state` with a critically-damped spring (no overshoot, no oscillation) at roughly 150ms to settle. Numbers use an odometer roll (§15.3), not a linear lerp — a rolling digit reads as a value changing, a lerping digit reads as a glitch.

If no `state` message has arrived for 500ms, oF freezes the last state and draws a small connection-lost indicator in a corner. It does not black out — a frozen table is far better on a contest floor than a dead one.

### 13.4 Fonts and sizes on the table

Scale factor: the stage is 1920 px across a 1524 mm table ⇒ **1.26 px per mm**. Cap height ≈ 0.7 × font size, so `font_px = mm_cap_height × 1.26 ÷ 0.7 = mm × 1.8`.

| Element | Cap height | Font size (en) | Font size (zh) |
|---|---|---|---|
| Running total, numeral | 45 mm | 80 px | 92 px |
| Total label | 16 mm | 28 px | 32 px |
| Bin item name | 20 mm | 36 px | 42 px |
| Bin weight / unit price | 14 mm | 26 px | 30 px |
| Button label | 18 mm | 32 px | 38 px |
| Voice hint strip | 12 mm | 22 px | 26 px |
| Recap line item | 14 mm | 26 px | 30 px |
| Developer overlay | — | 16 px | 16 px |

Chinese is set **15% larger than English at equal cap height** because CJK glyphs pack far more stroke detail into the same box and lose legibility first under projector blur.

Fonts: `Inter` for `en`, `Noto Sans SC` for `zh`. Two `ofTrueTypeFont` instances per size, selected by `state.locale`.

Rules that are not style preferences:
- **Dark ink on a light field, and set bold.** The field is bright by requirement (I9), so text can no longer win on brightness and there is no dark plate to sit on. Contrast has to come from stroke width, which is the one thing a bold face has more of — already the reason the bin labels use DejaVu Sans Bold rather than the regular cut. Halos and outline rings invert with it: dark rings on light ground, never light-on-light.
- **Load each font at its final display size.** Never load small and scale up — projected text at 3× scale is mud.
- **VERIFY the CJK range API before use.** oF 0.12's `ofTrueTypeFontSettings` supports adding Unicode ranges, but the exact enum name has changed across versions. Check the installed header. Loading the full CJK range at 42 px produces a very large atlas; if load time or VRAM becomes a problem, generate the exact glyph set from `data/locales/zh.json` and add only those ranges.
- **Halo and outline rings must be FILLED geometry. No stroke API of any kind produces a ring you can rely on.** An earlier version of this bullet said to use `ofPath` with `setStrokeWidth()` and never `ofSetLineWidth()`. **That instruction was wrong and is retracted — they are the same call.** VERIFIED in the installed oF 0.12.1, not remembered: `ofGLRenderer::draw(const ofPath &)` reaches `setLineWidth(shape.getStrokeWidth())`, which is `glLineWidth()`. So an unfilled `ofPath` *is* `ofSetLineWidth()` wearing a different name, and inherits the 1 px cap the bullet was written to avoid — Mesa on Intel, the ODYSSEY's driver family, is exactly where that bites. Worse, `ofGLProgrammableRenderer::setLineWidth()` has its `glLineWidth()` call **commented out**, so on the programmable renderer stroke width is ignored outright and every line is 1 px. This app is on the fixed-function renderer today only because `ofGLWindowSettings::glVersionMajor` defaults to 2; M8's fluid will force GL 3.2+ and take every stroked ring in the app to a hairline on the same day.
  - Rectangular rings: four filled bars (`UiLayer::drawRing` is the reference implementation). No tessellator, no winding rules, correct on both renderers.
  - Circular rings — the M5 dwell ring, M8's halos: a **filled** `ofPath` built from an outer arc and an inner `arcNegative`. Never two `ofDrawCircle` calls with the background colour punched through the middle: over a fluid there is no background colour to punch with.
  - This is the third API in this project's history that was trusted from memory and turned out not to do what the name says (`addTemporalForce` in §14.1, the CJK range enum below, this one). The rule in §0 exists because of exactly this.
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

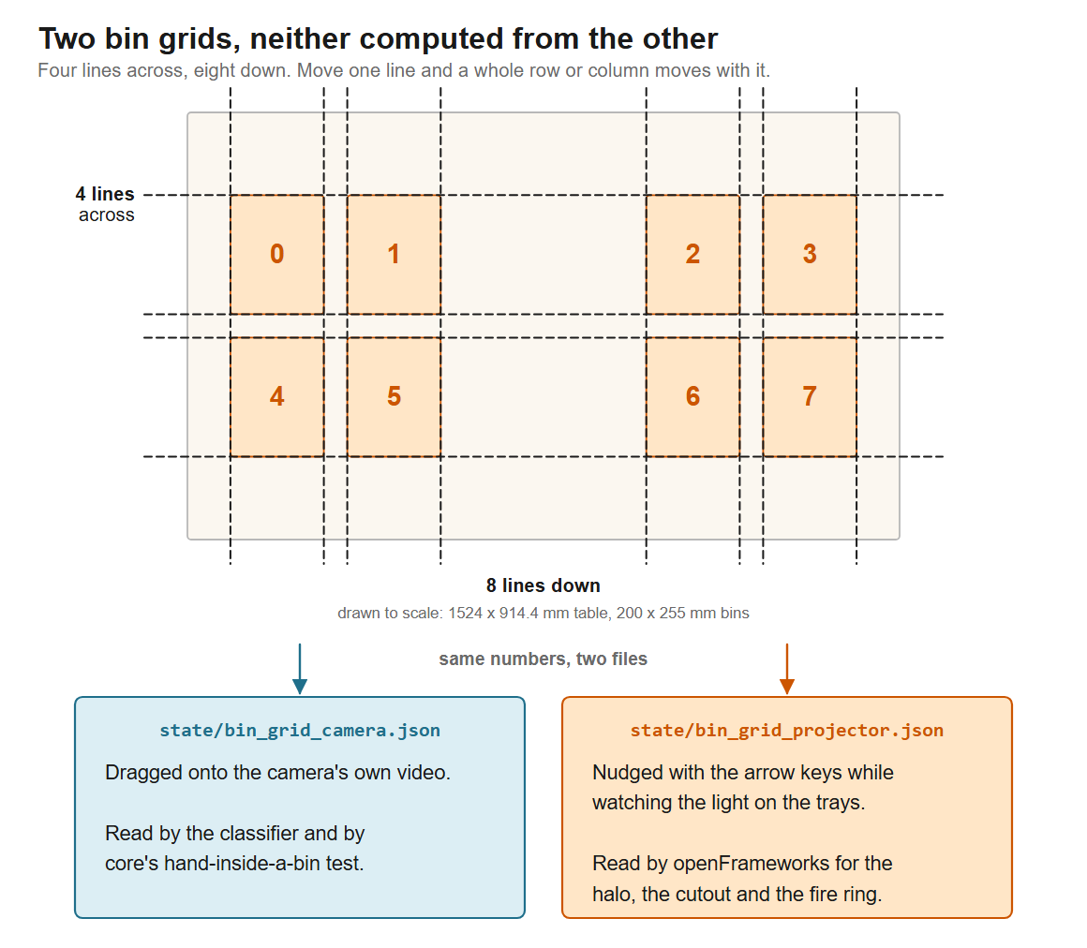
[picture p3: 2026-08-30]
docs/img/architecture-two-grids.png

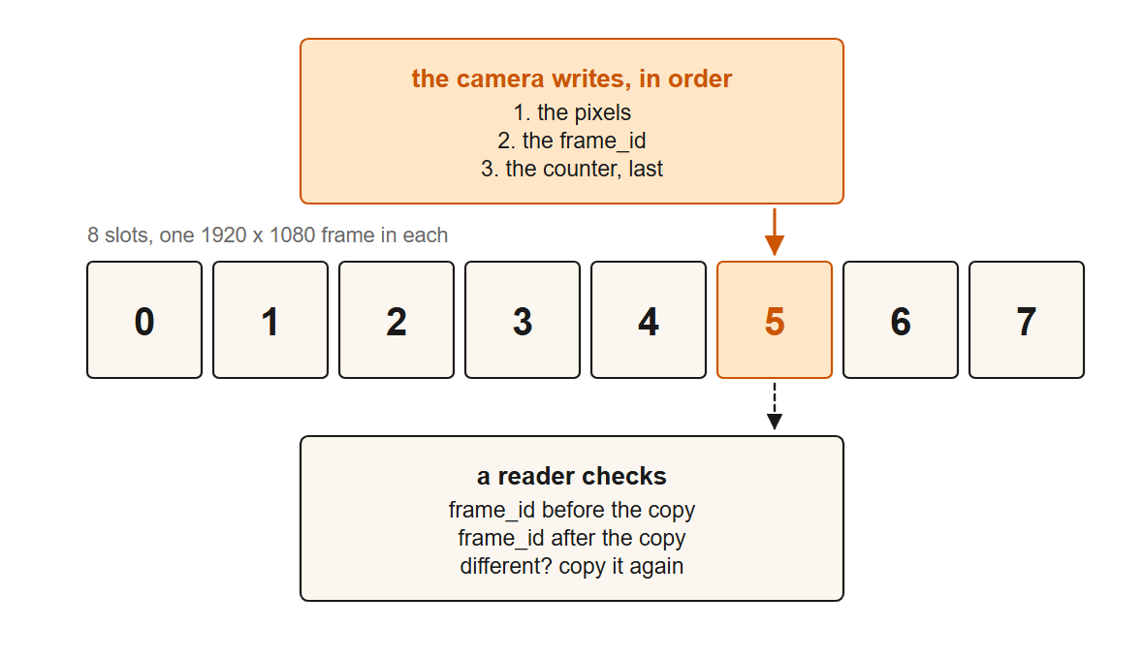
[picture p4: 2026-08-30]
docs/img/architecture-frame-ring.png

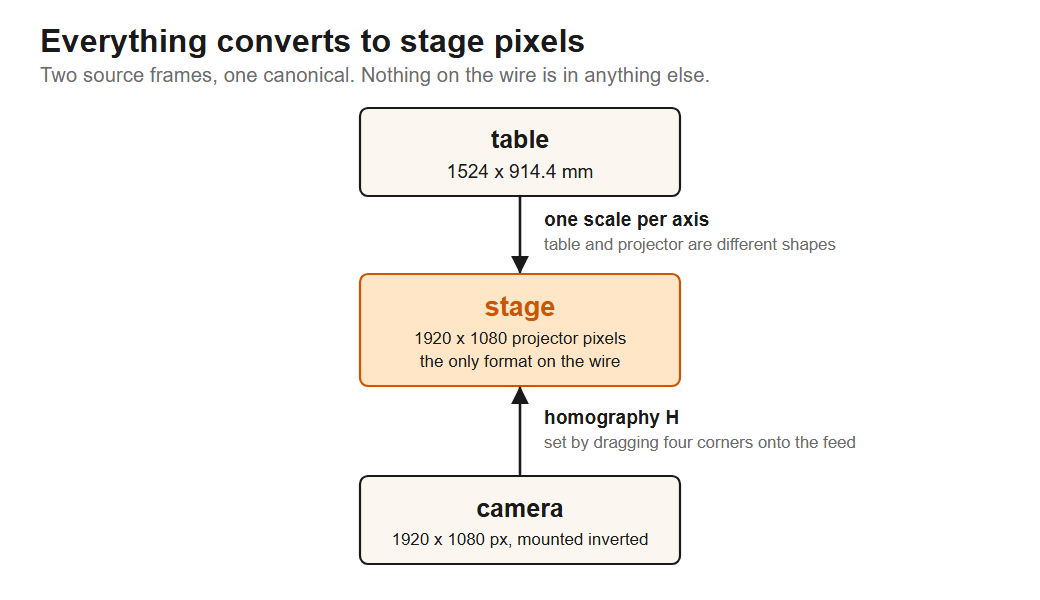
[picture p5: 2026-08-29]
docs/img/architecture-coordinate-spaces.png

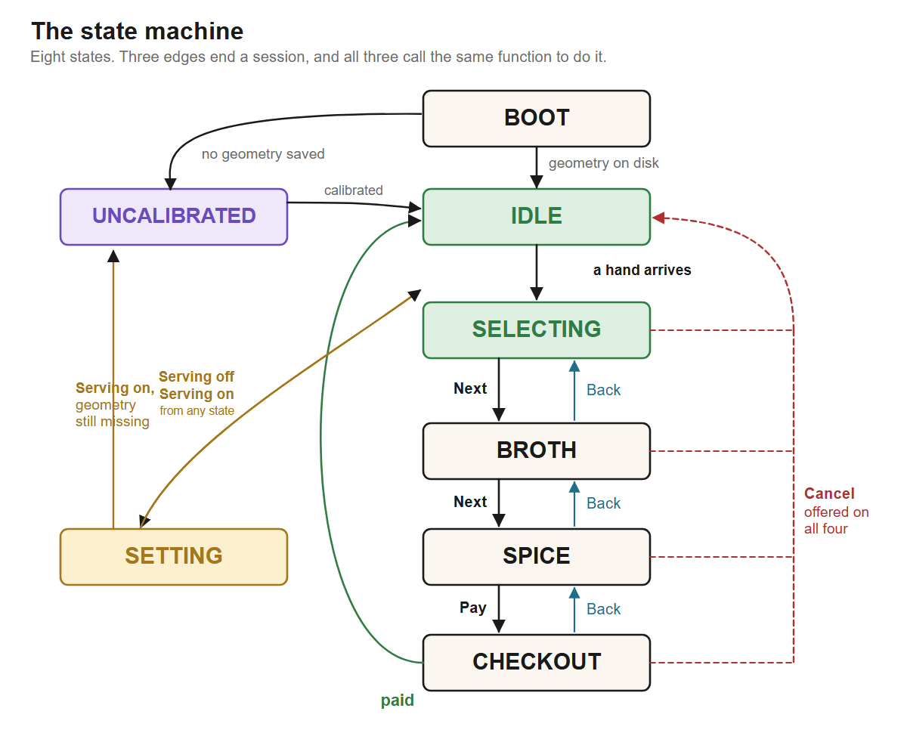
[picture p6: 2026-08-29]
docs/img/architecture-state-machine.png

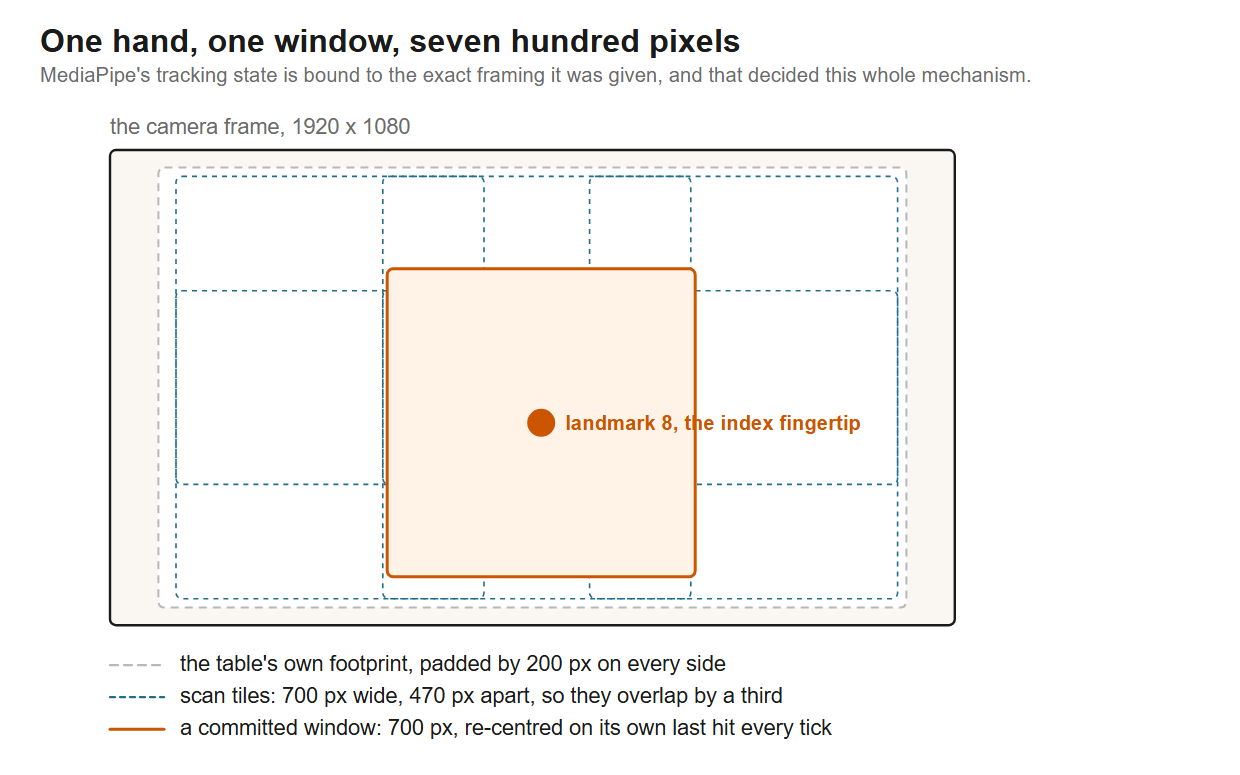
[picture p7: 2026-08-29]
docs/img/architecture-hand-window.png

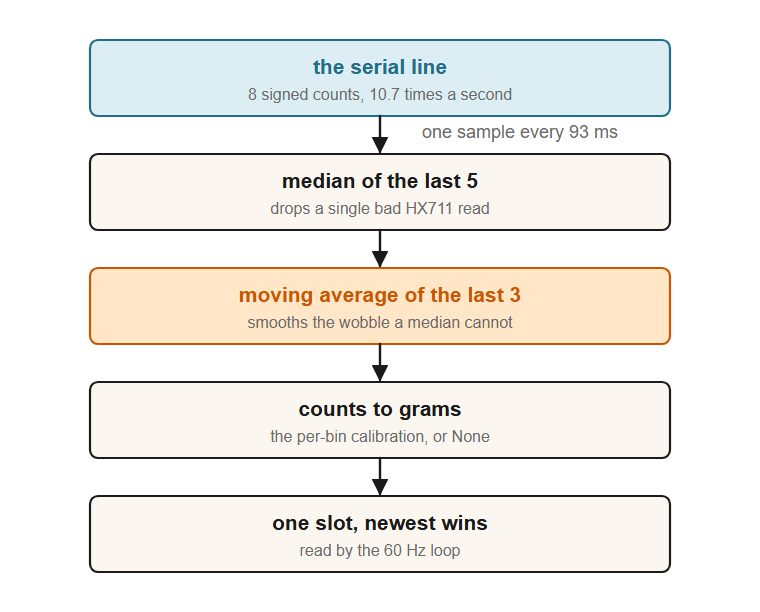
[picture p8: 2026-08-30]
docs/img/architecture-scale-filter.png

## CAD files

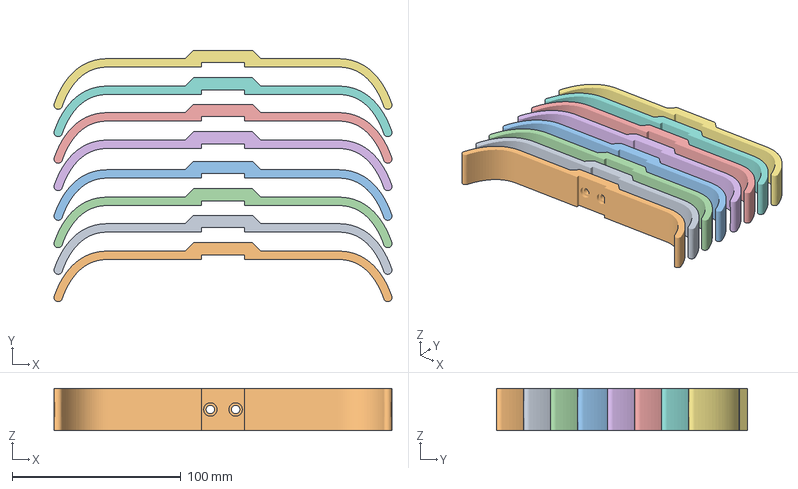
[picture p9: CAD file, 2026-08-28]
hardware/3d-printed/load_plate_short.3mf
200.5 x 149.1 x 25.0 mm
load_plate_short x 8

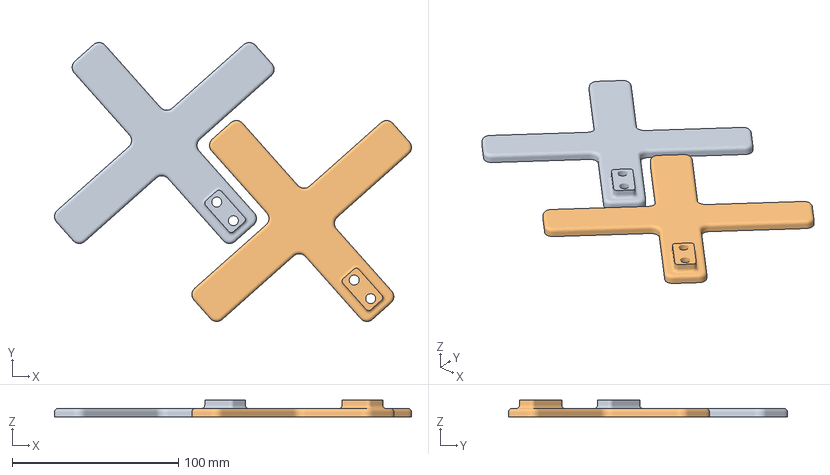
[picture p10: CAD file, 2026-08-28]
hardware/3d-printed/load_base.3mf
214.7 x 167.7 x 10.0 mm

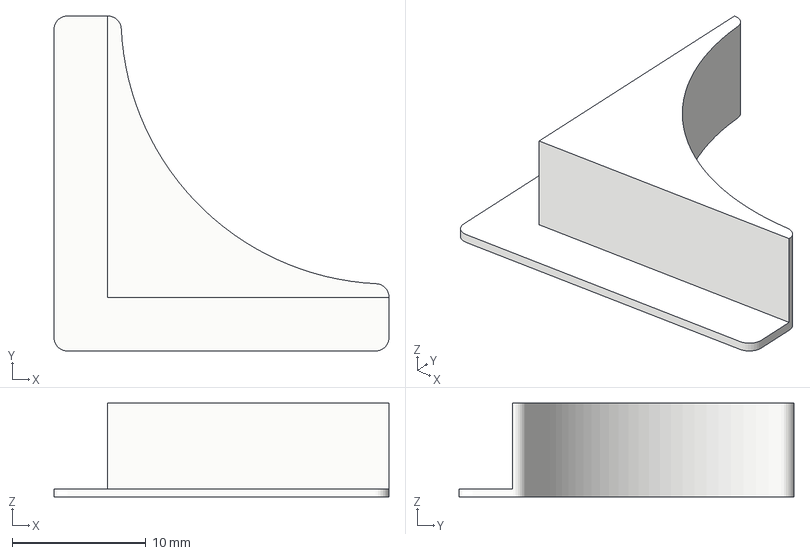
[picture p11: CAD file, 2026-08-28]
hardware/3d-printed/corner_plug.3mf
25.0 x 25.0 x 7.00 mm

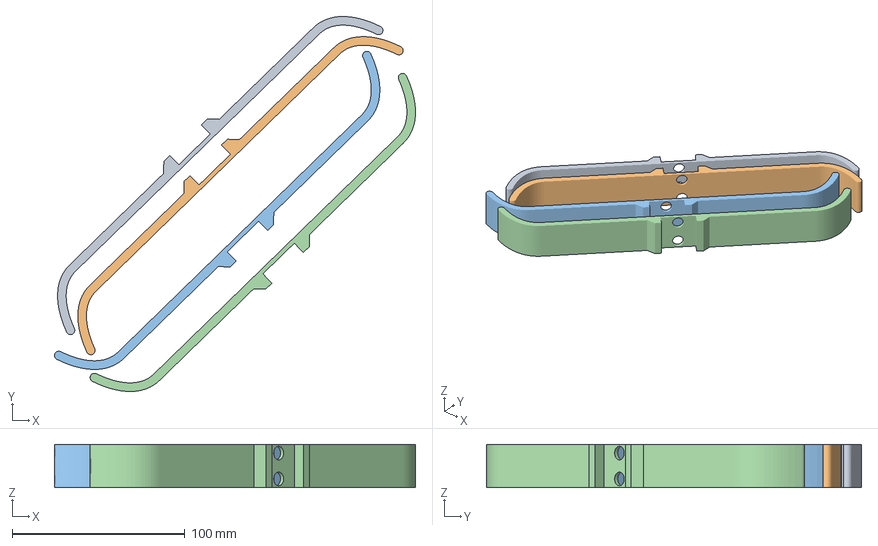
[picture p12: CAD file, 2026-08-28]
hardware/3d-printed/load_plate_long.3mf
209.1 x 217.2 x 25.0 mm
load_plate_long x 4

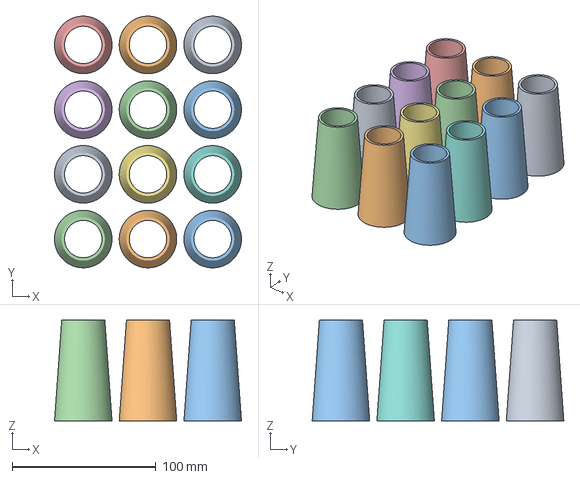
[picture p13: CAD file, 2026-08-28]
hardware/3d-printed/pillar.3mf
129.9 x 174.9 x 70.0 mm

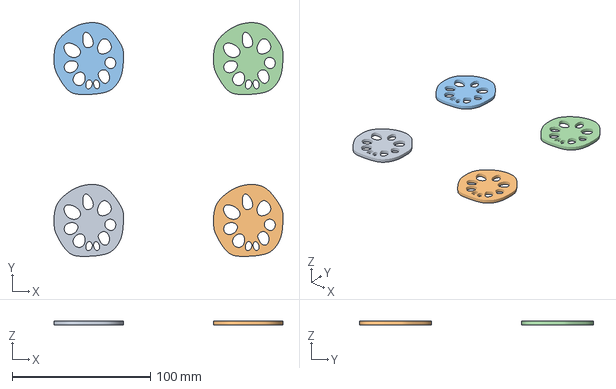
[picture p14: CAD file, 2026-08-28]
hardware/3d-printed/lotus_root.3mf
165.4 x 168.8 x 3.00 mm

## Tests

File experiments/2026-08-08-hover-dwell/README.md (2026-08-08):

# 2026-08-08 — hover dwell threshold

**Question:** how long must a hand stay inside a bin before that bin counts
as hovered — i.e. what should `HOVER_DWELL_MS` be?

**Answer: PROVISIONAL. 1000 ms stands, unchanged, because the data that
would have moved it is not trustworthy yet.** The measurement it rests on
predates a known hand-tracking fault and must be re-run from scratch, not
extended. See "why the answer is provisional" below.

---

## Why there is a threshold at all

A hand travelling from one bin to another passes over the bins in between.
Those pass-overs are real detections inside a real bin rect and are
indistinguishable from an intentional hover **except by how long they last**.
The threshold is the entire discrimination.

Too low and the table reacts to every bin on the way to the one the diner
wanted. Too high and a deliberate hover feels broken.

1000 ms was a guess, written into `TableGeometry.h` and commented as a
rig-tunable starting value rather than a derived dimension — there is no
chain it falls out of and nothing to calculate it from. This experiment
existed to replace the guess with a measurement.

## What was established first: the timer is correct

Separate question from the value, and settled independently.

30 hover cycles across all 8 bins. Every `IDLE -> HOVERED` fired between
**1000 and 1050 ms**. The overshoot is one tracker frame (33 ms at 30 fps),
with occasional two-frame steps where a dropped detection was credited its
real 66 ms of wall clock.

That spread is the proof the accumulator measures wall clock between
detections rather than app frames, and that the ~500 ms render hold is not
feeding it. Had the two timers been crossed, a 1000 ms hover would have
taken roughly 2000 ms of real time. It did not.

**The mechanism is sound. Only the number is in question.**

## The measurement, and why it needed instrumentation

A rejected pass-over is completely silent — it writes nothing, because
nothing happens. So a clean log is the expected shape of a threshold that
is working *and* of one set so high that nothing ever reaches it. Those are
not the same thing and the log could not tell them apart.

`DWELLING -> IDLE` logging was added, reporting the time banked at the
moment of reset. Resets under 100 ms are dropped: a hand clipping the corner
of a rect banks a few tens of ms, and those are the edge being touched at
all, not a pass-over.

### Result, n = 16

```
100 101 116 150 150 283 301 433 434 518 566 598 600 700 851 883

min       100 ms
median    434 ms
mean      424 ms
2nd max   851 ms
max       883 ms
```

Margin at 1000 ms: **117 ms**, about 3.5 tracker frames. Thin. And the max
is the statistic most likely to grow with more samples, not less.

On this data alone the recommendation was 1500 ms.

## Why the answer is provisional

**The accumulator resets on `/hand/none`.** That message is the tracker
positively reporting an empty frame, and it zeroes every bin immediately —
which is correct behaviour, and is what makes pass-over rejection work at
all.

But it means a detection dropout mid-crossing does not pause a sample. It
**truncates** it and starts a new one. Consequences, all in the same
direction:

- every logged pass-over is a **lower bound** on the real crossing duration
- the max **understates**, so the true worst case is ≥ 883 ms
- a crossing split into fragments under the 100 ms floor disappears
  entirely, so **n is undercounted too**

So unreliable tracking does not add noise around the true value — it biases
every sample short. That makes 1000 ms *less* safe than 117 ms of margin
suggests, not more.

Tracking is known to be unreliable right now for two independent reasons
(see the next-session notes): fixed camera exposure that does not compensate
when the room dims, and closed-fist poses that MediaPipe cannot resolve at
an overhead angle. Neither is fixed.

**Re-run 2g from scratch after tracking is fixed. Do not extend this data
set — samples taken before and after the fix are not the same measurement.**

## Decided along the way

### The §9 split, resolved

§9 records "colour merges instantly on hover — no dwell timer, because the
load cell confirms the actual pick", which appeared to contradict building a
dwell timer for bins at all. It does not. The two are different signals:

- **Instant colour on entry.** Commits to nothing, so it cannot be wrong —
  the load cell, not the hover, confirms the pick. No dwell required.
- **Dwelled progress drives the popup.** The popup is the committing
  action, and a popup firing on every bin a hand crosses is exactly the
  failure the threshold exists to prevent.

Only the second needs to clear the pass-over distribution.

### Cyan failed, and the reason generalises

Progress was first built as dim cyan on a white outline. **Rejected at the
table: very difficult to see at standing height.**

The failure was not the hue but the axis. A dimmed colour differs from the
white idle outline mostly in **brightness**, and brightness is what
projector light and ambient light are already fighting over on a white
plywood surface.

**Rule, now general to this project: distinguish states by HUE at full
value, never by brightness.**

Replaced with red on entry, green replacing the red along the same line as
progress — so the leftover red reads as the work remaining, and red-to-green
carries the meaning with no legend. Colour *values* remain unconfirmed on
the rig; the structure and the rule are what this experiment settled.

## Next

1. Fix hand tracking. Two separate problems — do not conflate them:
   fixed exposure with no compensation when dark, and closed-fist poses at
   ~80° overhead, which is not a lighting problem.
2. Measure the camera elevation angle (open since stage 1).
3. Re-run the pass-over measurement from scratch.
4. Run the legibility test that was never done: mid-reach, does the
   red-to-green ratio say how close to committing you are? If it only reads
   near-complete, that is an argument against the fill as an encoding, not
   for a longer threshold.

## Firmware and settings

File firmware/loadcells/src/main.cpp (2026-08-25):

// Load cell aggregator: 8x HX711 on a shared clock, raw counts to USB serial.
//
// Output, one line per conversion cycle:
//   raw <c0> <c1> <c2> <c3> <c4> <c5> <c6> <c7>
//
// Diagnostics are prefixed with '#' and are never confusable with data:
// core/scale.py's parse_line() accepts a line only if it is exactly the
// literal `raw` plus eight integers, and drops everything else silently.
//
// No tare, no scaling, no settled detection, no stored state. The link is
// one-directional; nothing is read from Serial.
//
// Why there is a heartbeat LED
// ----------------------------
// The XIAO's USB is the ESP32-S3's USB-Serial-JTAG peripheral, which lives in
// ROM and enumerates on power alone. A COM port therefore appears whether the
// sketch is running, hung, or crashed, and "the board is plugged in" says
// nothing about whether it is sending. The LED is the out-of-band answer:
//
//   solid on        still in setup() -- or setup() never finished
//   slow blink      ~1Hz, one toggle per 5 lines: cells read, data going out
//   triple flash    repeating: alive, but a cell is not reporting; see the
//                   '# fault:' lines for which one

#include <Arduino.h>
#include <HX711-multi.h>

static const int CELL_COUNT = 8;

static const byte SCK_PIN = D0;  // GPIO1, shared clock to all 8 HX711s

// One DT line per cell, index == bin number, matching BINS[] in
// src/TableGeometry.h: 0-3 far row left to right, 4-7 near row left to right.
// Indices are row-major across the whole table, so each island holds one pair
// from each row rather than a contiguous run:
//
//        left island        right island
//   far     0   1              2   3
//   near    4   5              6   7
//
// D3-D6 serve the left island, D7-D10 the right. The right island runs in
// descending pin order because D10..D7 sit top to bottom on that header, so
// the harness stays in physical order. D1 and D2 are unused; D2/GPIO3 is a
// strapping pin, sampled at reset.
static byte DT_PINS[CELL_COUNT] = {
    D3,   // bin 0, far left      GPIO4
    D4,   // bin 1, far c-left    GPIO5
    D10,  // bin 2, far c-right   GPIO9
    D9,   // bin 3, far right     GPIO8
    D5,   // bin 4, near left     GPIO6
    D6,   // bin 5, near c-left   GPIO43
    D8,   // bin 6, near c-right  GPIO7
    D7,   // bin 7, near right    GPIO44
};

// Printed alongside a fault so the message names the wire to go and check,
// not just the bin index. Same order as DT_PINS.
static const char *DT_LABELS[CELL_COUNT] = {
    "D3/GPIO4",  "D4/GPIO5",  "D10/GPIO9", "D9/GPIO8",
    "D5/GPIO6",  "D6/GPIO43", "D8/GPIO7",  "D7/GPIO44",
};

// The XIAO ESP32-S3's user LED sits between 3V3 and GPIO21, so the pin sinks
// it: LOW is lit.
#ifndef LED_BUILTIN
#define LED_BUILTIN 21
#endif
static const byte LED_PIN = LED_BUILTIN;
static const uint8_t LED_ON = LOW;
static const uint8_t LED_OFF = HIGH;

// An HX711 at its default 10 SPS converts every ~100ms. 400ms is four
// conversions of margin -- long enough never to trip on a healthy cell, short
// enough that a dead one is reported two and a half times a second rather than
// once. The slower first conversion after power-up is absorbed by the startup
// probe below, which has already waited before the first read is attempted.
static const uint32_t READY_TIMEOUT_MS = 400;

// One LED toggle per five lines. At the measured 10.7Hz that is a ~1.07Hz
// blink -- slow enough to read as a heartbeat rather than a flicker.
static const uint8_t HEARTBEAT_SAMPLES = 5;

// A fault repeats for as long as it lasts, but not at loop rate.
static const uint32_t FAULT_REPORT_MS = 2000;

// Heap-allocated so construction happens after Serial.begin(). The constructor
// performs a priming read, and until that read was given a timeout it could
// block forever, presenting as a dead device. See lib/HX711-multi/README.md.
static HX711MULTI *cells = NULL;

static bool ledLit = false;

static void ledSet(bool on) {
    ledLit = on;
    digitalWrite(LED_PIN, on ? LED_ON : LED_OFF);
}

static void ledFlashes(uint8_t times, uint16_t on_ms, uint16_t off_ms) {
    for (uint8_t i = 0; i < times; ++i) {
        ledSet(true);
        delay(on_ms);
        ledSet(false);
        delay(off_ms);
    }
}

// Why a silent line is silent. The HX711 drives DOUT push-pull, so it beats
// either internal pull resistor; if the line instead follows whichever pull is
// applied, nothing is driving it at all. That distinction is the difference
// between a wiring job and a board swap, so it is worth the four pinMode calls.
static const char *lineCharacter(byte pin) {
    pinMode(pin, INPUT_PULLUP);
    delayMicroseconds(50);
    int up = digitalRead(pin);
    pinMode(pin, INPUT_PULLDOWN);
    delayMicroseconds(50);
    int down = digitalRead(pin);
    pinMode(pin, INPUT);

    if (up == HIGH && down == LOW) {
        // Follows the pull both ways: open DT wire, or an HX711 with no power.
        return "floating";
    }
    if (up == HIGH && down == HIGH) {
        // Something is holding it high. The HX711 does that when it has no
        // conversion ready -- powered but not converting, or held in power-down
        // by a stuck-high PD_SCK on that board.
        return "driven-high";
    }
    if (up == LOW && down == LOW) {
        return "driven-low";
    }
    return "unstable";
}

// Prints "bin 1 D4/GPIO5 floating" for each set bit of `mask`, one per line.
static void printCellDiagnosis(uint32_t mask) {
    for (int i = 0; i < CELL_COUNT; ++i) {
        if (mask & (((uint32_t)1) << i)) {
            Serial.print("#   bin ");
            Serial.print(i);
            Serial.print(' ');
            Serial.print(DT_LABELS[i]);
            Serial.print(' ');
            Serial.println(lineCharacter(DT_PINS[i]));
        }
    }
}

// Prints "bins 2 5 (D10/GPIO9 D6/GPIO43)" for the set bits of `mask`.
static void printCellSet(uint32_t mask) {
    Serial.print("bins");
    for (int i = 0; i < CELL_COUNT; ++i) {
        if (mask & (((uint32_t)1) << i)) {
            Serial.print(' ');
            Serial.print(i);
        }
    }
    Serial.print(" (");
    bool first = true;
    for (int i = 0; i < CELL_COUNT; ++i) {
        if (mask & (((uint32_t)1) << i)) {
            if (!first) {
                Serial.print(' ');
            }
            Serial.print(DT_LABELS[i]);
            first = false;
        }
    }
    Serial.print(')');
}

// Watches every DT line for `window_ms` and returns a mask of the ones never
// seen low. A healthy HX711 pulls DOUT low at the end of each conversion and
// holds it there until clocked, and nothing clocks during the probe, so one
// conversion period is enough for a good cell to answer.
//
// The lines are pulled up for the duration: an unconnected pin floats and can
// read low by chance, which would report a missing cell as healthy. A real
// HX711 drives DOUT push-pull and walks over the internal pull-up easily, so
// this costs a good cell nothing and makes a missing one unambiguous.
static uint32_t probeDataLines(uint32_t window_ms) {
    uint32_t neverLow = 0;
    for (int i = 0; i < CELL_COUNT; ++i) {
        pinMode(DT_PINS[i], INPUT_PULLUP);
        neverLow |= ((uint32_t)1) << i;
    }
    delay(2);  // let the pull-ups settle before the first sample

    uint32_t start = millis();
    while (neverLow && (uint32_t)(millis() - start) < window_ms) {
        for (int i = 0; i < CELL_COUNT; ++i) {
            uint32_t bit = ((uint32_t)1) << i;
            if ((neverLow & bit) && digitalRead(DT_PINS[i]) == LOW) {
                neverLow &= ~bit;
            }
        }
        delay(1);
    }

    // Hand the pins back in the state HX711MULTI's constructor expects.
    for (int i = 0; i < CELL_COUNT; ++i) {
        pinMode(DT_PINS[i], INPUT);
    }
    return neverLow;
}

void setup() {
    pinMode(LED_PIN, OUTPUT);
    ledSet(true);  // solid until the first line goes out

    Serial.begin(115200);

    // Without this, a write with no host attached blocks on the CDC FIFO for
    // the default timeout on every line. The rig boots with nothing listening
    // more often than not; dropping those bytes is the correct trade.
    Serial.setTxTimeoutMs(0);

    // Give a host that is already open a moment to attach, so the banner and
    // the startup probe are not lost. Bounded, because usually nothing is
    // listening and the rig must come up regardless.
    uint32_t start = millis();
    while (!Serial && (uint32_t)(millis() - start) < 1500) {
        delay(10);
    }

    Serial.println();
    Serial.println("# hx711 loadcell aggregator, 8 cells, raw counts");
    Serial.print("# built ");
    Serial.print(__DATE__);
    Serial.print(' ');
    Serial.println(__TIME__);

    // Probe before constructing, so a stuck line is named rather than merely
    // timing out later. 500ms is five conversion periods.
    uint32_t silent = probeDataLines(500);
    if (silent == 0) {
        Serial.println("# probe: all 8 cells reporting");
    } else {
        Serial.print("# probe: no data line activity from ");
        printCellSet(silent);
        Serial.println();
        printCellDiagnosis(silent);
        Serial.println("# probe: floating = open DT wire or unpowered board;");
        Serial.println("# probe: driven-high = board powered but not converting");
    }

    cells = new HX711MULTI(CELL_COUNT, DT_PINS, SCK_PIN);
    cells->setReadyTimeout(READY_TIMEOUT_MS);

    Serial.println("# ready");
}

void loop() {
    static uint8_t beat = 0;
    static bool faulted = false;
    static uint32_t lastFaultReport = 0;

    long counts[CELL_COUNT];

    // readRaw() bypasses the library's tare offsets, which are never set here.
    // It returns false rather than hanging when a cell stops reporting, and
    // clocks nothing in that case -- so there is no half-read frame to print.
    if (!cells->readRaw(counts)) {
        uint32_t mask = cells->notReadyMask();

        if (!faulted || (uint32_t)(millis() - lastFaultReport) >= FAULT_REPORT_MS) {
            lastFaultReport = millis();
            Serial.print("# fault: not ready within ");
            Serial.print(READY_TIMEOUT_MS);
            Serial.print("ms, ");
            printCellSet(mask);
            Serial.println(" -- no data sent this cycle");
            // Repeated rather than printed once per episode: the fault usually
            // predates whoever opened the port, and it is what you watch while
            // reseating a connector.
            printCellDiagnosis(mask);
        }
        faulted = true;

        // Deliberately not the heartbeat pattern: the board is alive, so the
        // LED must not be dark, but nothing is being sent, so it must not look
        // like the ~1Hz blink either.
        ledFlashes(3, 40, 80);
        return;
    }

    if (faulted) {
        Serial.println("# ok: all 8 cells reporting again");
        faulted = false;
        beat = 0;
    }

    Serial.print("raw");
    for (int i = 0; i < CELL_COUNT; ++i) {
        Serial.print(' ');
        Serial.print(counts[i]);
    }
    Serial.println();

    // The heartbeat is driven by lines actually sent, not by a timer, so it
    // stops the moment the data does.
    if (++beat >= HEARTBEAT_SAMPLES) {
        beat = 0;
        ledSet(!ledLit);
    }
}

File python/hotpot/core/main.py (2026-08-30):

"""The core process: the one place that owns state.

What lives here:

  - the control server every other process dials into, and the client
    registry that turns hellos and heartbeats into the six status pips;
  - the staff view, pushing those pips and the Bins/Setup/Capture tabs to
    a browser over a WebSocket;
  - the pure domain modules (pricing, cart, binmap, i18n, fsm, menu,
    orders) held as Core's state and serialised into doc section 4.3's
    `state` message, sent to `of` at a fixed 60Hz;
  - the load-cell reader and calibrator (core/scale.py,
    core/calibrator.py), driven by the Bins tab over a second, lower-rate
    broadcast.

Real grams reach pricing every state tick: `_apply_scale_to_cart()` reads
`self.scale.read()` and feeds any bin with a non-None grams value into
Cart — `set_live_grams()` from then on, but `seed_live_grams()` the first
time, so a placeholder weight is never priced against a real one (see
cart.py). A bin the scale cannot weigh — uncalibrated, or no XIAO at all
— is left exactly where the developer panel's mock controls put it, which
is what doc section 12.8's "stays forever as a test harness" is for.

The SERVING/SETTING mode gates all of that. `_apply_scale_to_cart()`
returns immediately in SETTING, and `fsm.exit_setting()` refreshes every
bin's weight (via `_refresh_weights_from_scale`), re-baselines and locks
the bin map on the way out. Tare and Calibrate require SETTING, and the
tablet drives the mode with `set_mode`, answered by a broadcast `mode`
message.

This process must NEVER open the camera, touch MediaPipe, or hold a
frame (invariant I3).

Host and port are hardcoded to the doc section 4.1 defaults, same as
common/stub.py; `SCALE_PORT` likewise, since doc section 8.6's config
example has no serial-port key.
"""

from __future__ import annotations

import logging
import math
import threading
import time
from pathlib import Path
from typing import Any, Callable, Dict, Optional

from hotpot.classifier import ei_client, ei_deploy, ei_store
from hotpot.classifier import rf_client, rf_deploy, rf_store
from hotpot.common import atomicio, config, cursorbus, geometry, health, log, wire
from hotpot.core import (bin_grid, binmap, calibrator, cart, fsm,
                         geometry_store, hover, i18n, loadcell_cal, menu,
                         orders, pricing, scale)
from hotpot.core.web import server as web

_log = logging.getLogger("hotpot.core")

CONTROL_HOST = "127.0.0.1"     # doc 4.1: only sibling processes on this
                                # same machine ever dial the control port.
CONTROL_PORT = 8765            # doc 4.1: core.control_port default

# 0.0.0.0, not 127.0.0.1: the staff view is read from a tablet (doc
# section 12.1, "assume a tablet"), which reaches this over the LAN, not
# loopback. Binding to loopback would work on the dev machine and fail
# silently on the rig.
WEB_HOST = "0.0.0.0"
WEB_PORT = 8090                # doc 4.1: core.web_port default (was 8080;
                                # moved off it — Windows dev machines keep
                                # squatting it via a stale WSL2 portproxy
                                # relay to a stopped distro, see CLAUDE.md)

STATIC_ROOT = Path(__file__).resolve().parent / "web" / "static"

# core/main.py -> core -> hotpot -> python -> repo root. Same hardcoded-
# until-something-needs-config-loading rationale as the ports above.
DATA_DIR = Path(__file__).resolve().parents[3] / "data"

# Doc section 4.3: "sent at a fixed 60Hz, whether or not anything
# changed" — a fixed-rate stream is what lets oF's tweener trust silence
# never means "core is dead" (of/main.py checks staleness, not gaps).
STATE_HZ = 60.0
STATE_INTERVAL = 1.0 / STATE_HZ

# Every bin starts full of a fixed placeholder weight so the mock
# pick/put-back cycle (doc section 12.8) has something to remove grams
# from before any bin has a real scale reading — first boot, an
# uncalibrated bin, or no XIAO at all. Per bin, this is a one-time seed:
# _apply_scale_to_cart() replaces it with the real weight (via
# cart.seed_live_grams(), never plain set_live_grams() — see that
# module's docstring on why the hand-off needs its own entry point) the
# first time core/scale.py reports one, and never reads it again after
# that. Still needed as long as a bin can be diner-facing before it has
# been calibrated.
MOCK_SEED_GRAMS = 500.0

# Doc section 8.6's config example has no serial-port key, so this is
# hardcoded the same way CONTROL_PORT/WEB_PORT are. It matches the dev
# rig's XIAO, NOT the deploy machine's port, which waits on config
# loading like every other §8.6 key.
SCALE_PORT = "COM5"

# doc section 8.6's `camera.host_for_browser`/`camera.mjpeg_port` defaults —
# what the Live tab embeds in the `<img>` src, since the MJPEG server is
# camera's own HTTP listener on a different port than this process's. Constructor params, not read from config.py here directly
# (same reason cal_path/scale_open_port are params, not module reads): a
# Core built by a test must never depend on config/system.json. main()
# below is the one place that actually calls config.load().
CAMERA_HOST = "localhost"
CAMERA_PORT = 8081

# Doc section 12.7's dataset tree. Core never writes into it — the
# classifier does, because core never touches a frame (I3) — but core
# counts what is in it for the tab's per-label session counter.
CAPTURES_DIR = Path(__file__).resolve().parents[3] / "datasets" / "captures"

# Doc section 19.2/19.5's Edge Impulse link + fetched deployment — the
# Capture tab's "Edge Impulse" panel below drives ei_client.py/ei_store.py
# against these. EI_PROJECT_NAME is only used the first time `ei_link`
# creates a brand new Studio project; an already-linked project (today,
# `hotpot-ingredients`, id 1087506 — models/README.md) keeps whatever name
# it was created with, read back from ei_store.py.
EI_PROJECT_PATH = ei_store.DEFAULT_PATH
EI_PROJECT_NAME = "hotpot-ingredients"
MODELS_DIR = Path(__file__).resolve().parents[3] / "models"
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

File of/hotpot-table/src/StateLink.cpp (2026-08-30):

#include "StateLink.h"

#include "ofxTCPClient.h"
#include "ofLog.h"
#include "ofUtils.h"

#include <algorithm>

#ifdef _WIN32
	#include <windows.h>
#else
	#include <unistd.h>
#endif

namespace {
	const char * kTag = "StateLink";

	// No ofGetProcessId() in this oF version (VERIFIED — ofUtils.h has none).
	// The pid in `hello` is display-only on core's side (health.py's Entry.pid
	// is read by the staff view, never by any liveness decision), so a
	// platform pid is worth having but nothing here depends on its accuracy.
	long currentProcessId(){
#ifdef _WIN32
		return (long)GetCurrentProcessId();
#else
		return (long)getpid();
#endif
	}

	// doc §20.2's ladder, and wire.py's BACKOFF_START/BACKOFF_MAX exactly.
	const float kBackoffStart = 1.0f;
	const float kBackoffMax = 10.0f;

	// doc §4.2.
	const float kHeartbeatInterval = 1.0f;

	// wire.py's WELCOME_TIMEOUT: "a client that connects and is never
	// welcomed is talking to something that is not core."
	const float kWelcomeTimeout = 5.0f;

	// Poll granularity for the link thread. Small enough that a heartbeat
	// or a queued `stat` line never waits more than this to go out.
	const float kTick = 0.05f;

	// wire.py's MAX_LINE_BYTES, so a stream we can no longer trust to be
	// framed gets the same treatment on both ends: drop the link.
	const size_t kMaxLineBytes = 1 << 20;

	uint64_t nowMs(){
		using namespace std::chrono;
		return duration_cast<milliseconds>(steady_clock::now().time_since_epoch()).count();
	}
}

void StateLink::setup(const std::string & host, int port, const std::string & who){
	_host = host;
	_port = port;
	_who = who;
	_stop = false;
	_thread = std::thread(&StateLink::threadLoop, this);
}

void StateLink::shutdown(){
	_stop = true;
	if(_thread.joinable()){
		_thread.join();
	}
}

bool StateLink::hasState() const {
	std::lock_guard<std::mutex> lock(_stateMx);
	return _hasState;
}

StateLink::State StateLink::getState() const {
	std::lock_guard<std::mutex> lock(_stateMx);
	return _latest;
}

std::vector<StateLink::Event> StateLink::drainEvents(){
	std::vector<Event> out;
	std::lock_guard<std::mutex> lock(_evtMx);
	out.swap(_incomingEvents);
	return out;
}

float StateLink::secondsSinceLastState() const {
	std::lock_guard<std::mutex> lock(_stateMx);
	if(!_hasState){
		// Large rather than 0: "never connected" must not read as "just
		// updated", which is what the doc's 500ms freeze rule tests for.
		return 1.0e6f;
	}
	using namespace std::chrono;
	return duration<float>(steady_clock::now() - _lastStateAt).count();
}

bool StateLink::isConnected() const {
	return _connected.load();
}

void StateLink::sendStat(float fps, const std::string & keystoneFingerprint){
	// doc §4.5: telemetry only, fire-and-forget. sim_res/gpu_ms are
	// FluidLayer's numbers and are reported as zero — this link does not
	// read them back out of the sim.
	ofJson msg = {
		{"t", "stat"},
		{"fps", fps},
		{"sim_res", ofJson::array({0, 0})},
		{"gpu_ms", 0.0},
		{"dropped", 0},
		{"keystone_fingerprint", keystoneFingerprint},
	};
	std::lock_guard<std::mutex> lock(_outMx);
	_outQueue.push_back(std::move(msg));
}

void StateLink::sendLine(ofxTCPClient & tcp, const ofJson & obj){
	// dump()'s ensure_ascii defaults to false in this nlohmann version, the
	// same choice wire.encode() makes on purpose (doc: "\\u codes would
	// triple [Chinese labels'] size and make a tcpdump unreadable"). Not
	// passed explicitly here so a link-time version mismatch would show up
	// as a build error against the documented default, not a silent switch
	// back to escaping.
	tcp.sendRaw(obj.dump() + "\n");
}

void StateLink::pollIncoming(ofxTCPClient & tcp, std::string & recvBuf){
	// receiveRawBytes bypasses ofxTCPClient's own "[/TCP]" framing entirely
	// (see the class comment) — this is nothing but a non-blocking recv().
	char chunk[8192];
	for(;;){
		int n = tcp.receiveRawBytes(chunk, sizeof(chunk));
		if(n <= 0){
			break;   // no data right now; isConnected() is how a real close is noticed
		}
		recvBuf.append(chunk, (size_t)n);

		size_t nl;
		while((nl = recvBuf.find('\n')) != std::string::npos){
			std::string line = recvBuf.substr(0, nl);
			recvBuf.erase(0, nl + 1);
			if(line.empty()){
				continue;   // blank keepalive lines are not messages (wire.py parity)
			}

			ofJson j = ofJson::parse(line, nullptr, /*allow_exceptions*/ false);
			if(j.is_discarded() || !j.is_object()){
				ofLogWarning(kTag) << "dropped an unparseable line (" << line.size() << " bytes)";
				continue;
			}

			const std::string t = j.value("t", "");
			if(t == "welcome"){
				// Handshake completion is handled inline in connectOnce();
				// a welcome should not normally arrive again mid-session,
				// but if it does there's nothing to act on beyond noting it.
				continue;
			}
			if(t == "state"){
				State parsed;
				if(parseState(j, parsed)){
					std::lock_guard<std::mutex> lock(_stateMx);
					_latest = parsed;
					_hasState = true;
					_lastStateAt = std::chrono::steady_clock::now();
				}
				continue;
			}
			if(t == "evt"){
				// doc §4.4: AudioBus's cue. Queued rather
				// than acted on here — this is the link thread, and
				// AudioBus/ofApp live on the render thread, same reason
				// `state` goes through `_latest` instead of being drawn
				// from here directly. Dropped once the queue is full
				// rather than grown without bound: fire-and-forget by
				// design (doc §4.4's own "if oF misses one... nothing
				// breaks"), so a stalled render thread loses the newest
				// events, not memory.
				std::lock_guard<std::mutex> lock(_evtMx);
				if(_incomingEvents.size() < kMaxQueuedEvents){
					_incomingEvents.push_back({j.value("kind", ""), std::move(j)});
				}
				continue;
			}
		}

		if(recvBuf.size() > kMaxLineBytes){
			ofLogError(kTag) << "line exceeded " << kMaxLineBytes << " bytes — resetting link";
			tcp.close();
			recvBuf.clear();
			return;
		}
	}
}
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

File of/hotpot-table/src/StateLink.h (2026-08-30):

#pragma once

#include "ofJson.h"

#include <atomic>
#include <chrono>
#include <mutex>
#include <string>
#include <thread>
#include <vector>

class ofxTCPClient;

// The control link, oF's side (doc §4, §20). oF is a TCP client; core is
// the one listener in the system (python/hotpot/common/wire.py's docstring
// says this outright: "core is the TCP server for every control link,
// everyone else is a client and reconnects with backoff"). This class is
// the C++ mirror of wire.Client, and it has to agree with wire.py on every
// byte, because the two are the only things that ever talk this protocol:
//
//   - one JSON object per line, newline-terminated, UTF-8, no other framing.
//   - a client opens with `hello`, waits for `welcome`, then heartbeats
//     every 1000ms (doc §4.2) until the link drops.
//   - reconnect backoff starts at 1s, doubles, caps at 10s (doc §20.2),
//     and a client must never give up — core not being up yet is the
//     normal state of the world at boot.
//
// ofxTCPClient imposes its own framing: send() appends "[/TCP]" plus a
// literal NUL byte, unconditionally, regardless of setMessageDelimiter (see
// ofxTCPClient.cpp). That NUL would land inside the next line from wire.py's
// point of view and fail json.loads on it. This class therefore never calls
// send()/receive() — only sendRaw() and receiveRawBytes() — and does its own
// newline splitting below, the same job LineReader does in wire.py.
//
// Runs its own thread, deliberately, the same way wire.Client does: a
// blocking connect() (ofxTCPManager::Connect() blocks even in "non-blocking"
// mode, per its own setup() — SetNonBlocking() is only called *after*
// Connect() returns) must never happen on oF's render thread, or a core
// that is slow to start freezes the table before a single frame draws.
// ofApp only ever reads the latest parsed state through a mutex; it must
// never block waiting for one.
class StateLink {
public:
	struct Bin {
		int i = 0;
		std::string label;
		std::string sub;
		float grams = 0.0f;
		float picked = 0.0f;
		double price = 0.0;
		std::string hl = "none";        // none|hover|picking|picked|lowstock|disabled
		std::string stock = "ok";
		bool resolved = false;

		// doc §4.3's `rect`, in STAGE space, [x,y,w,h].
		// Core derives it from the camera-space rect staff dragged, through
		// H_cam->stage (doc §5.3), and it is what oF frames the plate and
		// the light-pass cutout against.
		//
		// hasRect is false until core has both a homography and eight
		// saved rects. It has to be an absence, not a plausible rectangle
		// at the origin: an uncalibrated table falls back to
		// TableGeometry.h's CAD layout, which is visibly approximately
		// right, whereas a rect at 0,0 would look like a rendering bug.
		bool hasRect = false;
		float rx = 0.0f, ry = 0.0f, rw = 0.0f, rh = 0.0f;

		// doc §4.3's `info` (VISUAL_LAYER.md §8's info box). All three
		// arrive ALREADY RESOLVED, including the "kcal /
		// 100g" unit, for the same reason `sub` carries "/100g" rather
		// than oF appending it: I2 puts every diner-facing word on core's
		// side of the wire, so a second locale changes one JSON file and
		// no C++.
		//
		// `diet` is the one machine-readable value of the three — "veg",
		// "nonveg" or "egg" — because oF picks a colour and a dot from it
		// (drawInfoBox) rather than printing it. Empty on an unresolved
		// bin, and empty means DRAW NOTHING: doc §8's "Idle: invisible.
		// No fill, no border. Not an empty bordered box."
		std::string diet;   // veg|nonveg|egg, or "" for an unresolved bin
		std::string meta;   // right-hand slot: "74 kcal / 100g", resolved
		// One sentence on what the ingredient is LIKE, so a diner can
		// choose it. Never an instruction — the kitchen cooks this food,
		// not the table. See pricing.Item.description for the full rule.
		std::string desc;
	};

	// doc §4.3's `widgets`, and §9.4's dwell fraction.
	// oF draws these and times NOTHING: `dwell` arrives as a 0..1 fraction
	// core computed, so the ring's fill is core's answer, not a second
	// clock here that could disagree with the one that actually fires.
	struct Widget {
		std::string id;      // cancel|confirm|broth:<id>|spice:<n>
		std::string kind = "button";   // "button" | "option"
		std::string label;   // already resolved in the current locale (I2)
		float x = 0.0f, y = 0.0f, w = 0.0f, h = 0.0f;   // stage space
		float dwell = 0.0f;  // 0..1
		bool enabled = true;
		std::string style = "primary";
		// Whether the pointer is inside this widget RIGHT NOW, which
		// is core's answer (it owns the hit test, doc §9.4) rather than a
		// second one derived here from `dwell > 0`. That derivation would
		// be wrong for the first frame of a hover, when the accumulator
		// is still at zero.
		bool hover = false;
		// Whether this option is the one the diner has LOCKED IN — a
		// completed dwell, held until they complete a dwell on a
		// different one. Independent of `hover`, and that independence is
		// the whole point: a diner can hover a second broth to read its
		// info box and take their hand away without changing anything.
		//
		// Core owns it (`core/hover.Widget.selected`) for the same reason
		// core owns `hover`: it is the thing that will be written to the
		// order, and a second answer derived on this side could disagree
		// with the one that bills.
		bool selected = false;
		// A glyph oF could draw `iconCount` times. INERT: nothing in
		// UiLayer reads these and core does not send them — the spice
		// screen draws plain option plates like the broth screen. The
		// fields stay on the wire because they are generic (a name and a
		// count), but there is no live producer to demonstrate them.
		std::string icon;
		int iconCount = 0;
		int maxIconCount = 0;
		// The info box's content while this widget is hovered — a broth
		// or a spice level has one, Cancel and Confirm do not. Same three
		// fields and the same rules as Bin's, so drawInfoBox can take
		// either without caring which it got.
		bool hasInfo = false;
		std::string diet;    // veg|nonveg|egg, or "" (a spice level is not food)
		std::string meta;    // the right-hand slot: "22 kcal / 100g", "Very spicy"
		std::string desc;
		// doc §18.1's "a colour swatch each", hex, empty for no swatch.
		std::string swatch;
	};
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

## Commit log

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2026-08-07 Add VS 2026 toolset (v145) fix and generated project files
    VS 2026 ships MSBuild under v180 with toolset v145, not v143 —
    projectGenerator's default v143 fails MSB8020 on a VS 2026-only
    machine. hotpot-table.vcxproj is hand-retargeted to v145 in all
    configs; CLAUDE.md documents the fix and the build command.
    [main.cpp]
2026-08-07 Fullscreen test pattern on projector monitor
    Monitor index is read from bin/data/display.txt (created with "0" if
    missing), never hardcoded. All connected monitors are enumerated via
    glfwGetMonitors() and logged before the window is created.
    draw() paints a static alignment pattern on black: edge border,
    diagonals, centre crosshair, 100px grid, corner circles, and a
    dimensions/framerate readout.
    [main.cpp]
2026-08-08 Set logger channel explicitly at startup
    Any ofLogNotice call crashed the app with 0xC0000005. The fault was
    in ofLog::channel() (libs/openFrameworks/utils/ofLog.cpp:27), whose
    function-local static shared_ptr<ofBaseLoggerChannel> is read while
    still null - its lazy initialiser never runs on this toolchain.
    Probe 1: calling ofSetLoggerChannel() first makes all logging work.
    Probe 2: with no explicit channel, the first log crashes wherever it
    happens - from ofApp::setup() after window creation, not just from
    main(). Window creation is not a factor; the only variable is whether
    the channel was set explicitly.
    Also removes /FORCE:MULTIPLE (ForceFileOutput) from the app link.
    It was investigat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
    [main.cpp]
2026-08-08 Target the projector monitor reliably before going fullscreen
    settings.monitor alone does not put the window on the requested
    monitor. oF creates a plain windowed window first and defers
    setFullscreen() to the first frame, where ofAppGLFWWindow::
    getCurrentMonitor() resolves the target by point-testing the
    window's top-left against each monitor rect.
    Positioning at the monitor origin exactly is not enough: Windows
    shifts a decorated window a few pixels into its invisible frame
    border. Asking for (-1920,139) yielded (-1921,132) - outside the
    monitor rect on both axes - so getCurrentMonitor() found no match,
    returned its fallback of 0, and fullscreen landed on the primary
    2560x1440 display. o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
    [main.cpp]
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2026-08-08 Describe the eight bins in table mm
    The bin positions are not free numbers: each one is a running total of a
    chain of edge margins, bin widths and gaps that has to span the plywood
    exactly. Writing only the totals would lose that, and the next person to
    change a bin size would have no way to see which other numbers move with
    it. So the chains are recorded as comments and the totals are checked
    against TABLE_W_MM / TABLE_H_MM at compile time.
    The checks use a 0.01 mm tolerance rather than ==. Neither 177.4 nor
    914.4 is representable in binary, so the Y chain lands within an ulp of
    TABLE_H_MM instead of exactly on it, and an exact comparison would be
    relying on a rounding tie going the right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
    [TableGeometry.h]
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2026-08-08 Nudge the whole bin pattern by hand
    The eight tray modules are independent with no shared rigid base, so the
    real cutouts sit where the build put them rather than where CAD says.
    Arrow keys shift all eight together, 1 mm a press and 5 mm with shift,
    and s writes the result to bin/data/bin_offsets.json for setup() to pick
    up next run. 1 mm is already finer than the calibration's own ~2.9 mm
    mean reprojection error, so the limit is what can be seen on plywood.
    This corrects only the error common to all eight bins. A bin that is off
    on its own needs a per-bin offset, which is deliberately not here yet.
    The offset is applied to the bins and NOT to the calibration dots: those
    are the reference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
    [TableGeometry.h]
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2026-08-08 Hover a bin by dwelling over it
    A hand crossing the table passes over every bin between where it started
    and where it is going, and those pass-overs are real detections inside a
    real bin. Only their duration tells them apart from a hover, so each bin
    accumulates time while a hand is inside it and resets the moment one is
    not. No decay: a hand oscillating over two bins must not bank both.
    HOVER_DWELL_MS is 1000 and is a starting guess, not a derived dimension.
    It is commented as such next to the layout chains, which are the opposite
    kind of number.
    Two things this had to avoid:
    The hit test goes through binRectPx(), the same rect the black fill is
    drawn from, so it carries the bin_offsets.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
    [TableGeometry.h]
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2026-08-09 Add the load cell firmware, raw counts only
    XIAO ESP32S3, 8x HX711 on a shared clock on D0, one DT per cell on
    D1, D3-D9. D2 is skipped: GPIO3 is a strapping pin sampled at reset,
    and an HX711 holding DOUT at power-up would vote on the boot mode.
    The firmware prints "raw" plus 8 decimal counts and does nothing else.
    No tare, no calibration, no settled detection, no stored state, and
    nothing is ever read from Serial.
    HX711MULTI is heap-allocated in setup() rather than constructed as a
    global. Its constructor does a priming read that blocks until every DT
    line is low, so a global would stall ahead of USB enumeration and the
    board would present as dead rather than as waiting on absent hardwar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
    [main.cpp]
2026-08-09 Wire the load cells by island, not by row
    DT lines move to D3-D10, freeing D0's neighbours: D3-D6 serve the left
    island, D7-D10 the right, so each island's harness runs in header order
    and neither crosses the 440 mm centre gap.
    The first pass mapped D3-D6 to bins 0-3, which is wrong. BINS[] in
    src/TableGeometry.h is row-major across the whole table, so 0-3 is the
    far row and spans both islands. The islands are bins 0,1,4,5 and
    2,3,6,7:
    left island right island
    far 0 1 2 3
    near 4 5 6 7
    Right island pin order descends because D10..D7 sit top to bottom on
    that header, which mirrors the left island rather than crossing over
    itself.
    D1 and D2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
    [main.cpp]
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2026-08-10 M0.6 stub main.py for camera, tracker, classifier, voice
    Each connects, says hello, heartbeats, and prints HOTPOT-READY,
    sharing that sequence through a new common/stub.py rather than
    repeating it four times. Readiness fires the moment the client and
    heartbeat are started, not once core has welcomed it back — camera
    is tier 1 and core is tier 2 (doc section 10.3), so gating camera's
    readiness on a core connection would deadlock the start order.
    Also notes a pre-existing run.py pidfile race in CLAUDE.md, found
    while smoke-testing this against run.py: starting several tier-3
    children at once collides on state/run.pid on Windows. Processes
    still come up, print ready, and shut down clean with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
    [main.py]
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2026-08-10 M1.2 add core/pricing.py, cart.py, binmap.py, i18n.py, fsm.py
    Doc section 21 build item 2: the five pure domain modules, with states
    BOOT/IDLE/SELECTING only for the FSM as the build item specifies.
    - binmap.py: Bin/BinMap, doc 8.2's 8-bin state and 9.3's resolved()
    confidence-floor check, atomicio-backed load/save. A missing
    bin_map.json loads as 8 fresh unresolved bins (first-boot, doc 9.1).
    - cart.py: start_g/live_g/shown_g per bin. removed_grams() is I4's
    absolute-weight difference, never a summed delta. set_live_grams()
    is the one entry point for "the scale now reads this" and applies
    the doc 9.2 display deadband — shown_g snaps to truth, it does not
    creep and does not ig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
    [binmap.py, cart.py, fsm.py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]
2026-08-10 M1.3 wire pricing/cart/binmap/i18n/fsm into core/main.py's 60Hz state broadcaster
    Build item 3 (doc section 21). Core now loads the catalogue and English
    locale at startup, hand-seeds an 8-bin BinMap one-to-one from the new
    Catalogue.ids(), and hand-seeds Cart at 500g/bin so the mock pick cycle
    has weight to remove. A dedicated thread sends doc section 4.3's `state`
    message to `of` only, at a fixed 60Hz with resynchronising deadlines
    (same pattern as health.Heartbeat._run). fluid/widgets/overlay are sent
    in the documented shape but inert, since M8 and M6 don't exist yet.
    8 new tests in test_core_main.py's TestStateBroadcast drive Cart/BinMap
    directly and check message shape, seeded bins, se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
    [main.py, pricing.py]
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2026-08-11 Fix rendering and i18n bugs found running M1's acceptance test
    All found on the physical rig while working through doc section 21's
    M1 human acceptance test, not by inspection.
    - UiLayer::drawBin left the draw colour at white (ofSetColor(255)) after
    drawing the bin outline, and drawTotal never set its own colour either
    — both inherited it. The content FBO's background is also flat white
    (Stage::beginContent's ofBackground(255)), so every bin label, price,
    and the running total were being drawn white-on-white: invisible
    except for anti-aliased edge noise, which read as blurry/overlapping
    text. Doc section 13.4 is explicit this is wrong ("dark ink on a light
    field, and set bol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
    [StateLink.cpp, StateLink.h, UiLayer.cpp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]
2026-08-11 Display the deadbanded grams AND their price, not one of each
    Found auditing M1 against the doc, not on the rig.
    core/main.py's _bin_msg took `picked` from cart.shown_g (deadbanded, I5)
    but computed `price` from cart.removed_grams (truth), and _total_msg used
    pricing.total(), also truth. So a plate could read "45g" beside the price
    of 51g: pick 45g then 6g from bin 0 and the table said 45g / Rs 9.18,
    when 45g of curly noodles is Rs 8.10. M1's acceptance test still passed
    because it only checks the settled 171g total.
    The real cost lands at M2. The deadband exists so the projected number
    stops twitching; load-cell noise moves removed_g continuously, so the
    running total — the largest thin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
    [main.py, pricing.py]
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2026-08-11 Move the plate ring outside the cutout, and fix doc 13.4's stroke rule
    UiLayer::drawBin stroked a 3mm outline on the bin rect. Stage's light
    pass stamps opaque white over the CUTOUT rect — the bin grown by
    CUTOUT_MARGIN_MM — last, and that is 10mm past the bin edge while the
    stroke reached 1.5mm. So every frame drew the outline and then buried it.
    Nothing of it ever reached the projector: not the outline, not the 1.06x
    pick pop (max reach 10.9px against a 12.6px patch), and not the highlight
    colour. Since the ring carried the whole of doc 4.3's `hl`, I8 —
    "distinguish states by hue" — had no rendering channel at all. That is M1
    work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
    [UiLayer.cpp, UiLayer.h]
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2026-08-11 M2.1 add core/loadcell_cal.py — the two-point maths and its state file
    Doc section 21's M2 lists calibration as build item 3 and core/scale.py
    as item 2, but the dependency runs the other way: settle detection is
    specified in grams (section 9.5, "within ±2g"), grams need a calibration,
    so the maths has to exist before the thread that consumes it. Built in
    dependency order, not list order.
    Kept free of the serial port on purpose. atomicio.py's docstring names
    this file as the one number in the system that *silently mis-bills* when
    it is wrong, and everything that could make it wrong — the two-point
    subtraction, the sign, section 9.6's sanity check, the section 8.3 round
    trip — is now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
    [loadcell_cal.py]
2026-08-11 Stop bin labels falling back to the hidden training label
    core/main.py built every plate's label with
    label = item.names.get(self.locale, item.id)
    so any item a locale had not translated was captioned with `item.id` —
    the hidden training label — on the projected surface. Reverting the fix
    and rerunning makes a plate read `curly_noodle`, which is what the
    regression test asserts against.
    The rule the bug broke was implicit in doc §8.1 and is now written down
    there. `id` and `class_name` are hidden; `names` is the only thing a
    diner reads. They are two vocabularies, not two spellings of one: the
    label names something cheap to buy, photograph and train on, and the
    display name is th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
    [main.py, pricing.py]
2026-08-11 M2.2 add core/scale.py — the load-cell serial thread
    Build item 2. Owns the serial port: the parse (verified against
    firmware/loadcells/src/main.cpp, not doc 4.9), a median filter,
    staleness, settle detection, and the 2s capture windows M2.1's
    loadcell_cal.py said would live here.
    median_window is a constructor parameter and not a constant, because
    the rig runs at 10.7Hz and not doc 4.9's 78Hz: median-of-5 spans 465ms
    here, and if that lag shows on the table the fix is a smaller window.
    Stale (>0.5s) reports counts=None, which reaches grams_all(None) and
    comes back as eight Nones — a dead XIAO and an uncalibrated cell reach
    pricing by the same route and neither can bill. The thread reo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
    [scale.py]
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2026-08-11 M2.3 add core/calibrator.py — calibration wired end to end
    Closes build item 3. The seam where a capture window becomes a saved
    calibration: scale.capture() -> loadcell_cal.tare/calibrate ->
    state/loadcell_cal.json, and the only writer of that file. Doc 12.4's
    two buttons call it. Nothing constructs one yet — core/main.py is build
    item 5, and the wiring order it needs is in the module docstring.
    One shared Calibration: the Calibrator takes reader.cal and has no cal
    parameter, so it cannot calibrate a copy. A copy would save a perfectly
    good file the live reading never picks up, and nothing would look broken
    until someone weighed a plate by hand.
    "Bin 3 reads 500 g" is a second measurem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
    [calibrator.py]
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2026-08-11 M2.5 wire real grams into pricing — M2 build items 1-5 all code-complete
    Core._apply_scale_to_cart() feeds scale.read() into Cart every state
    tick, replacing the M1 mock seed as Cart's ongoing source once a bin
    has a real reading. cart.seed_live_grams() handles the one-time hand-off
    per bin so the gap between the mock seed and a real weight is never
    priced as a phantom pick. state.overlay.kind now flips to "error" when a
    bin that was billing from real weight goes dark — the doc gap M2.4 named
    and asked to be revisited here. Mock pick/put-back is untouched for any
    bin the scale can't weigh.
    9 new tests (366 total), two mutations checked red. Run against the live
    XIAO on COM5; the physica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
    [cart.py, main.py]
2026-08-11 Draw the M2 fault overlay on the table — oF parsed overlay.kind but never rendered it
    state.overlay.kind was already on the wire and StateLink already parsed
    it, but nothing drew it: bullet 5 of the M2 acceptance test ("table shows
    a fault overlay") had no visual to check. The doc gives no design for
    `error` (only the enum), so the design was proposed and reviewed before
    writing any oF code: UiLayer::drawErrorOverlay() is a 72px top-edge banner
    reusing doc §14.5's own "banner strip" pattern and the staff view's fault
    colour (--red #e05d5d, ink #2a0000), text "SCALES OFFLINE — NOT BILLING"
    on the already-loaded 36px font. Bins and the total keep drawing
    underneath, frozen, same as §13.3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
    [UiLayer.cpp, UiLayer.h]
2026-08-11 Replace calibration keypad with a text field for physical keyboard entry
    The Bins tab's Calibrate step used a 12-button on-screen keypad for
    entering the reference mass. Swapped it for a standard number input
    (prefilled with DEFAULT_REF_MASS_G, auto-selected on open, Enter
    submits) so an operator with a physical keyboard can just type the
    weight instead of tapping digits one at a time. Doc §12.4 and CLAUDE.md
    updated to match; calibrator.py's default and sanity check are
    untouched.
    [calibrator.py]
2026-08-11 Freeze cart billing for a bin while its Tare/Calibrate wizard is open
    _apply_scale_to_cart() fed every real scale reading straight into Cart
    with no way to tell staff moving weights for calibration apart from a
    diner picking food. The instant calibrate() succeeded it seeded Cart to
    the reference mass still sitting in the bin, and then lifting that mass
    back out — the ordinary next step of the wizard — priced as a diner
    pick of the whole calibration weight.
    doc section 9.1's real fix is a STAFF FSM state that refuses to bill and
    re-baselines the whole cart on exit; that milestone hasn't been built
    yet (fsm.py only has BOOT/IDLE/SELECTING), so this is the narrow version
    scoped to the Bins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
    [main.py]
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2026-08-11 M2.6e fix six things the first run on the dev machine showed
    None of these is a logic bug and the milestone was fully tested before any
    of them was visible. That is the point of running it.
    1. The banner said "SETTING — NOT BILLING" — jargon aimed at nobody who
    reads it. The table is the one surface with no operator filter on it; a
    diner is looking at it. Both banners now lead with the same headline,
    NOT SERVING, with the state as a subline (setting the table / scales
    offline) and the hue carrying the rest (I8).
    2. **The banner covered the far row's item names.** Section 14.5 said "a
    persistent banner strip along the top edge" and that is what was built,
    72px full wid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
    [UiLayer.cpp, UiLayer.h, calibrator.py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]
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2026-08-11 M2.6g shrink the plate label and mirror it about the pot
    Two things, both from looking at the table rather than at the code.
    1. The near row and the far row drew the same two rows of text in opposite
    orders. Far row read price-then-name going outward from the pot; near
    row read name-then-price. Both now go ring -> price/grams -> name
    reading outward, so the two halves of the table mirror each other the
    way the bins themselves do. The near row is a MIRROR of the far row's
    block, not a copy of its top-to-bottom order — that distinction is what
    the comment in the else branch is there to hold.
    2. Doc section 13.4 fixed the sizes at 36px and 26px, and that was a guess
    mad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
    [UiLayer.cpp]
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2026-08-11 enlarge the table brand mark and stack the banner below it, not over it
    drawH was hardcoded to fit inside the old 104px banner strip (80px after
    margin) — too small to read from a distance and the reason the mark
    looked tiny. Promoted to a named constant, kBrandHeightPx = 220, with
    its own top margin (kBrandTopMarginPx) instead of being centred inside
    kBannerHeightPx.
    The brand mark and the SETTING/error banner no longer share one strip
    and swap places. draw() now always draws the mark (when loaded); the
    banner never disappears it, and drawBanner's panel is shifted down by
    kBrandTopMarginPx + kBrandHeightPx + kBrandBannerGapPx so it sits below
    the mark's bottom edge instead of overlapping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
    [UiLayer.cpp]
2026-08-11 shrink the brand mark so it clears the bins with real margin
    At 220px tall the mark's drawn width (526px) nearly filled the whole
    529px-wide pot-gap column, leaving ~1.5px of margin on each side —
    it read as touching the neighbouring bin boxes in a real framebuffer
    capture even though it never geometrically overlapped them (different
    x-range). 170px tall leaves ~61px clear on each side and ends at
    y=190, above the far row's bin tops (y=~209) with room to spare.
    Verified with a real framebuffer capture (bin/data/screenshots/,
    'p' key) against the actual built exe, not a mockup.
    Builds clean (msbuild, Debug x64, 0 errors; only the pre-existing
    LNK4075 warning).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
    [UiLayer.cpp]
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2026-08-12 Stop a camera readback from becoming a permanent lock
    The dashboard feed had a yellow cast the OS camera app did not. Cause was
    a loop, not a bad value: run 1 left auto-WB on and read back 6500 K,
    main.py recorded it to state/camera_settings.json, and run 2 read that
    file back as prior_settings and turned auto-WB OFF to pin 6500 K under
    projector light. Every run after inherited it, so the fault looked like
    the camera rather than the file.
    The 2026-08-12 fix that stopped WindowsCapture forcing autos off on a
    fresh run was only half of it. It stopped run 1 freezing a bad value but
    left run 1 advertising its read-backs as if they were a calibration, and
    run 2 believed them.
    CaptureInfo gains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
    [main.py]
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2026-08-12 Restore the dot detection the old solver had measured
    The 2026-08-12 rig run reported "6 of 15 dots used, 4 not found". M4.2's
    dots.py detects at one fixed threshold on the raw frame, and
    tools/calibration/solve_homography.py - still in this repo - records why
    that cannot work here, with numbers taken on this rig:
    the plywood runs ~29 to ~58 grey ACROSS ONE FRAME, because the
    projector does not light the table evenly and the camera views it at an
    angle, while a dot sits only ~25-50 grey levels above whatever is under
    it
    Those two ranges overlap. A dim dot on the dark end of the board is
    darker than bare board on the bright end, so no single cut separates
    every dot from the table. T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
    [main.py]
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2026-08-12 Revert the dot-detection threshold sweep, measured worse on the rig
    Approved revert. The 2026-08-12 sweep+top-hat change was never run before
    shipping, and running it showed why that was the wrong instinct: ground
    truth from a real coarse-pass frame with 4 known corner dots gave a plain
    fixed threshold of 150, top-4-by-area, 4 of 4 correct. detect_best's
    sweep, with or without the top-hat, got 0-1 of 4 - its "longest stable
    run" tie-break was locking onto a room lamp's plateau, not the dots'.
    classifier/main.py._detect_dots no longer calls detect_best automatically
    - back to plain detect_dots, with threshold still overridable on the
    wire for the developer panel. dots.detect_best and
    dots.fl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
    [main.py]
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2026-08-12 ROI-crop the fine dot pass to the table footprint, and reorient the Setup tab's feed the same way
    M4i measured the fine pass finding only 6 of 15 grid dots because a room
    lamp outside the table fragments into blobs the same size as a real dot
    once the field inverts to black. The fix: derive the table's own camera-
    space footprint from the coarse fit (already confirmed 4/4 every run)
    and crop the classifier's detector to it before the fine pass looks.
    Measured on the rig: 6/15 -> 10, 11, 11 of 15 across three consecutive
    solves, all "good". An A/B (ROI margin bumped to cover the whole frame)
    confirms a later run of failures was a room light getting brighter mid-
    session, not a regression in t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
    [main.py]
2026-08-12 Add GeometryStore.fit_from_corners, the manual 4-corner calibration math
    First step of replacing the dot-projection solve with an operator
    clicking the table's 4 real corners on the live feed. Correspondence is
    pinned to click order (front-left/front-right/back-right/back-left), never
    inferred from screen position, so it doesn't repeat the 180-degree-mount
    trap order_quad hits. No wiring or UI yet - pure math and tests only.
    [geometry_store.py]
2026-08-12 Wire manual_calibrate: 4 clicked corners over the socket, a saved homography out
    Second step of the manual calibration replacement. _handle_manual_calibrate
    mirrors _handle_calibrate_dots' save sequence (set_homography, clear_verified,
    save_homography, seed rects if none exist) but is synchronous - no pattern
    projection, no classifier round trip, so it can't block a tablet's thread.
    Gated on setting mode, same reason set_rects is. 10 new over-the-wire tests,
    including the 180-degree-mount case end to end. Still no UI - the Setup tab
    has nothing yet to send a manual_calibrate message.
    [main.py]
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
